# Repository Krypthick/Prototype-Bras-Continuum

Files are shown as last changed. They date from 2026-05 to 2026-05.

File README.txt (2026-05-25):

Base:

base_housing:
Le boîtier principal agit comme une base pour le bras. Il utilise des inserts chauffants filetés et des boulons M3.
Il contient :
	-circuit principal
	-circuit des pilotes pas à pas
	-circuit du système de gestion de batterie
	-les batteries
	-interrupteur
	-prise cylindrique DC

==============================
base_battery_retainer:
La pièce qui maintient les batteries en place.

==============================
base_motion_motor_housing:
Couvercle qui s'attache au boîtier avec des boulons M3 et tient les moteurs pas à pas.

==============================
base_fixed_segment:
Premier segment.

==============================
base_spacer_fixed_segment:
Espaceur entre (base_fixed_segment) et (base_motion_motor_housing), fixé avec des boulons M5. Fournit l'espace nécessaire pour les poulies attachées au réducteur.

============================================================
Gearbox:

gearbox_motor_gear:
Engrenage attaché et entraîné par le moteur pas à pas. Engrenage soleil.

==============================
gearbox_planet_gear:
Engrenage planète, aussi appelé satellite. Il y en a trois pour avoir un réducteur stable.

==============================
gearbox_ring_gear:
L'engrenage fixé au moteur pas à pas avec des boulons M3 a aussi comme fonction de contenir les pièces du réducteur.

==============================
gearbox_orbit:
La pièce qui relie les trois engrenages planètes et est attachée à l'arbre avec des boulons et écrous M4.

==============================
gearbox_shaft:
L'arbre attaché aux engrenages planètes et auquel on attache la poulie.

==============================
gearbox_shaft_attachment:
La poulie qui tient la corde permettant le mouvement du bras.

======================================================
Hand:

hand_segment:
Le dernier segment qui tient le support de la main avec des boulons et écrous M5 et tient la fin de la corde.

==============================

hand_motor_finger_mount:
Le support qui tient le petit moteur pas à pas avec des boulons M3 ainsi que les deux doigts de la pince avec des boulons M5.

==============================

hand_gripper:
Le doigt de la pince qui contient un roulement à billes 606z.

==============================

hand_bearing_M5_spacer:
La pièce qui relie le boulon M5 de diamètre 5 mm et le roulement à billes ayant un diamètre intérieur de 6 mm.

======================================================
Manette:

manette_housing:
Boîtier de la manette qui contient le circuit de la manette, la batterie 9V et le joystick. Il utilise des inserts chauffants filetés et des boulons M3.

==============================
manette_lid:
Le couvercle du boîtier de la manette attaché avec des boulons M3.

==============================
manette_pin:
La pièce qui permet d'utiliser les boutons de la manette plus facilement depuis l'extérieur.

======================================================
Segment:

La pièce principale qui guide la corde et donne la flexibilité nécessaire pour le mouvement du bras. Chaque segment a un boulon et un écrou M4, mais aussi une boule filetée de 10 mm de diamètre qui permet la rotation entre les différents segments.

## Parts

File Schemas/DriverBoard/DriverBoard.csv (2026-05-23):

Reference | Qty | Value | MAN | MPN | DPN | Footprint | Datasheet
A1,A2,A3,A4 | 4 | Pololu_Breakout_A4988 |  |  |  | Footprints:MODULE_A4988_STEPPER_MOTOR_DRIVER_CARRIER | https://www.pololu.com/product/2980/pictures
C1,C2,C7,C8 | 4 | 100uF | Würth Elektronik | 865080343009 | 732-8419-6-ND | Footprints:WCAP-ASLI_6.3X5.5_DXL_ | ~
C3,C4,C5,C6 | 4 | 100nF | KEMET | C0603C104K5RACTU | 399-C0603C104K5RACTUCT-ND | Capacitor_SMD:C_0603_1608Metric_Pad1.08x0.95mm_HandSolder | ~
C_Bulk1 | 1 | 1000uF | Chemi-Con | APSG160ELL102MJB5S | 565-3621-ND | Footprints:CHEMI-JB5 | ~
D1 | 1 | LED | Lite-On Inc. | LTST-C171KGKT | 160-1426-1-ND | LED_SMD:LED_0603_1608Metric_Pad1.05x0.95mm_HandSolder | ~
H1,H2,H3,H4 | 4 | MountingHole | - | - | - | MountingHole:MountingHole_3.2mm_M3_DIN965_Pad | ~
J1 | 1 | Conn_02x08_Counter_Clockwise | Molex | 0702461601 | WM9221-ND | Footprints:CONN_7024616xx_MOL | ~
J2 | 1 | XT30 | DFRobot | FIT0586 | 1738-1436-ND | Connector_AMASS:AMASS_XT30U-F_1x02_P5.0mm_Vertical | ~
M1,M2,M3,M4 | 4 | Stepper_Motor_bipolar | - | - | - | Footprints:CONN_SDA-41791_M450_04_MOL | http://www.infineon.com/dgdl/Application-Note-TLE8110EE_driving_UniPolarStepperMotor_V1.1.pdf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
R1 | 1 | 1k5 | Panasonic Electronic Components | ERA-3AEB152V | P1.5KDBCT-ND | Resistor_SMD:R_0603_1608Metric_Pad0.98x0.95mm_HandSolder | ~
R2,R3,R4,R5 | 4 | 10k | YAGEO | RC0603FR-0710KL | 311-10.0KHRCT-ND | Resistor_SMD:R_0603_1608Metric_Pad0.98x0.95mm_HandSolder | ~
TP1 | 1 | Test 1A | - | - | - | TestPoint:TestPoint_Pad_2.5x2.5mm | ~
TP2 | 1 | Test2A | - | - | - | TestPoint:TestPoint_Pad_2.5x2.5mm | ~

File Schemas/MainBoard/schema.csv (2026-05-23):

Reference | Qty | Value | MAN | MPN | DPN | Footprint
R23 | 1 | 270k | YAGEO | RC0603FR-07270KL | 311-270KHRCT-ND | Resistor_SMD:R_0603_1608Metric_Pad0.98x0.95mm_HandSolder
R18 | 1 | 10k | YAGEO | RC0805JR-0710KL | 311-10KARCT-ND | Resistor_SMD:R_0805_2012Metric_Pad1.20x1.40mm_HandSolder
R16 | 1 | 60k | YAGEO | RT0603BRD0760KL | 13-RT0603BRD0760KLCT-ND | Resistor_SMD:R_0603_1608Metric_Pad0.98x0.95mm_HandSolder
R4 | 1 | 470 | YAGEO | RC0603JR-07470RL | 311-470GRCT-ND | Resistor_SMD:R_0603_1608Metric_Pad0.98x0.95mm_HandSolder
R3 | 1 | 52.3k | YAGEO | RC0603FR-0752K3L | 311-52.3KHRCT-ND | Resistor_SMD:R_0603_1608Metric_Pad0.98x0.95mm_HandSolder
R1,R6,R7,R8,R9,R10,R12 | 7 | 10k | YAGEO | RC0603FR-0710KL | 311-10.0KHRCT-ND | Resistor_SMD:R_0603_1608Metric_Pad0.98x0.95mm_HandSolder
J5 | 1 | Conn_01x04 | Würth Elektronik | 61300411121 | 732-5317-ND | Connector_PinHeader_2.54mm:PinHeader_1x04_P2.54mm_Vertical
R17 | 1 | 470k | Vishay Dale | CRCW0805470KJNEA | 541-470KACT-ND | Resistor_SMD:R_0805_2012Metric_Pad1.20x1.40mm_HandSolder
R13,R14,R15 | 3 | 0 | Vishay Dale | CRCW08050000Z0EA | 541-0.0ACT-ND | Footprints:RESC2012X50N
L2 | 1 | 10uH | Vishay Dale | IHLP4040DZER100M01 | 541-1295-1-ND | Footprints:IND_IHLP-4040DZ_VIS
U1 | 1 | TPS54331DR | Texas Instruments | TPS54331DR | 296-26991-1-ND | Footprints:SOIC127P599X175-8N
PS1 | 1 | TPS62162DSGR | Texas Instruments | TPS62162DSGR | 296-43671-1-ND | Footprints:SON50P200X200X80-9N
R19,R20,R21 | 3 | 220 | TE Connectivity Passive Product | CRGCQ0805F220R | A129741CT-ND | Resistor_SMD:R_0603_1608Metric_Pad0.98x0.95mm_HandSolder
L1 | 1 | 2.2uH | Taiyo Yuden | BRL3225T2R2M | 587-2165-1-ND | Footprints:INDC3225X170N
C5,C14 | 2 | 10uF | Taiyo Yuden | LMK212BJ106KG-T | 587-1300-1-ND | Capacitor_SMD:C_0805_2012Metric_Pad1.18x1.45mm_HandSolder
U3 | 1 | STM32F103C8T6 | STMicroelectronics | STM32F103C8T6 | 497-6063-ND | Footprints:QFP50P900X900X160-48N
D5 | 1 | ESDA5V3L | STMicroelectronics | ESDA5V3L | 497-6632-1-ND | Package_TO_SOT_SMD:SOT-23-3
R2,Ren1 | 2 | 100k | Stackpole Electronics Inc | RMCF0603FT100K | RMCF0603FT100KCT-ND | Resistor_SMD:R_0603_1608Metric_Pad0.98x0.95mm_HandSolder
U4 | 1 | CP2102N-A02-GQFN28R | Silicon Labs | CP2102N-A02-GQFN28R | 336-5890-1-ND | Footprints:IC_CP2102N-A02-GQFN28R
C24 | 1 | 4.7uF | Samsung Electro-Mechanics | CL10A475KP8NNNC | 1276-1044-1-ND | Capacitor_SMD:C_0805_2012Metric_Pad1.18x1.45mm_HandSolder
C20,C21 | 2 | 1uF | Samsung Electro-Mechanics | CL10B105KP8NNNC | 1276-1946-1-ND | Capacitor_SMD:C_0603_1608Metric_Pad1.08x0.95mm_HandSolder
C11 | 1 | 100pF | Samsung Electro-Mechanics | CL10C101JB8NNNC | 1276-1008-1-ND | Capacitor_SMD:C_0603_1608Metric_Pad1.08x0.95mm_HandSolder
C10 | 1 | 10nF | Samsung Electro-Mechanics | CL10B103KB8NNNC | 1276-1009-1-ND | Capacitor_SMD:C_0603_1608Metric_Pad1.08x0.95mm_HandSolder
C9 | 1 | 4.7nF | Samsung Electro-Mechanics | CL10B473KB8NNNC | 1276-1063-1-ND | Capacitor_SMD:C_0603_1608Metric_Pad1.08x0.95mm_HandSolder
C6,C7,C8,C12 | 4 | 22uF | Samsung Electro-Mechanics | CL10A226MP8NUNE | 1276-1274-1-ND | Capacitor_SMD:C_0805_2012Metric_Pad1.18x1.45mm_HandSolder
C2 | 1 | 100uf | Rubycon | 35ZLH100MEFC6.3X11 | 1189-1300-ND | Footprints:CAP_YX_6P3X11_RUB
R11 | 1 | 1k5 | Panasonic Electronic Components | ERA-3AEB152V | P1.5KDBCT-ND | Resistor_SMD:R_0603_1608Metric_Pad0.98x0.95mm_HandSolder
R5 | 1 | 8.2k | Panasonic Electronic Components | ERJ-3EKF8201V | P8.20KHCT-ND | Resistor_SMD:R_0603_1608Metric_Pad0.98x0.95mm_HandSolder
Q1,Q2 | 2 | SS8550DTA | onsemi | SS8550DTA | SS8550DTACT-ND | Footprints:TO-92-3L_5P33X5P2_ONS
J1 | 1 | Conn_02x08_Counter_Clockwise | Molex | 0702461601 | WM9221-ND | Footprints:CONN_7024616xx_MOL
D8 | 1 | LEDR | Lite-On Inc. | LTST-C171KGKT | 160-1426-1-ND | LED_SMD:LED_0805_2012Metric_Pad1.15x1.40mm_HandSolder
D7 | 1 | LEDO | Lite-On Inc. | LTST-C171KGKT | 160-1426-1-ND | LED_SMD:LED_0805_2012Metric_Pad1.15x1.40mm_HandSolder
D6 | 1 | LEDV | Lite-On Inc. | LTST-C171KGKT | 160-1426-1-ND | LED_SMD:LED_0805_2012Metric_Pad1.15x1.40mm_HandSolder
D2 | 1 | LED | Lite-On Inc. | LTST-C171KGKT | 160-1426-1-ND | LED_SMD:LED_0805_2012Metric_Pad1.15x1.40mm_HandSolder
FB1 | 1 | 120 | Laird-Signal Integrity Products | MI0603M121R-10 | 240-2375-1-ND | Inductor_SMD:L_0603_1608Metric_Pad1.05x0.95mm_HandSolder
C28 | 1 | 100nF | KEMET | C0805C104K5RACTU | 399-C0805C104K5RACTUCT-ND | Capacitor_SMD:C_0805_2012Metric_Pad1.18x1.45mm_HandSolder
C25,C26 | 2 | 10pF | KEMET | C0603C100J5GACTU | 399-C0603C100J5GACTUCT-ND | Capacitor_SMD:C_0603_1608Metric_Pad1.08x0.95mm_HandSolder
C1,C3,C4,C13,C15,C16,C17,C18,C19,C22,C23,C27 | 12 | 100nF | KEMET | C0603C104K5RACTU | 399-C0603C104K5RACTUCT-ND | Capacitor_SMD:C_0603_1608Metric_Pad1.08x0.95mm_HandSolder
U2 | 1 | ESP32-WROOM-32E | Espressif Systems | ESP32-WROOM-32E-N4 | 1965-ESP32-WROOM-32E-N4CT-ND | Footprints:XCVR_ESP32-WROOM-32E__16MB_
J3 | 1 | XT30 | DFRobot | FIT0586 | 1738-1436-ND | Connector_AMASS:AMASS_XT30U-M_1x02_P5.0mm_Vertical
D1,D3,D4 | 3 | D_Schottky | Comchip Technology | CDBC560-G | 641-1127-1-ND | Footprints:CDBC-G
SW2,SW4 | 2 | BOOT | C&K | PTS636SK25FSMTR LFS | CKN12330-1-ND | Button_Switch_SMD:SW_Tactile_SPST_NO_Straight_CK_PTS636Sx25SMTRLFS
SW1 | 1 | EN | C&K | PTS636SK25FSMTR LFS | CKN12330-1-ND | Button_Switch_SMD:SW_Tactile_SPST_NO_Straight_CK_PTS636Sx25SMTRLFS
J2,J4 | 2 | USB_B_Micro | Amphenol ICC (FCI) | 10118192-0001LF | 609-4613-1-ND | Footprints:AMPHENOL_10118192-0001LF
Y1 | 1 | 16MHz | Abracon LLC | ABM8G-16.000MHZ-18-D2Y-T | 535-10267-1-ND | Crystal:Crystal_SMD_2520-4Pin_2.5x2.0mm
TP1,TP2,TP3,TP4,TP5 | 5 | TestPoint | - | - | - | TestPoint:TestPoint_Pad_1.5x1.5mm
H1,H2,H3,H4 | 4 | MountingHole | - | - | - | MountingHole:MountingHole_3.2mm_M3_DIN965_Pad

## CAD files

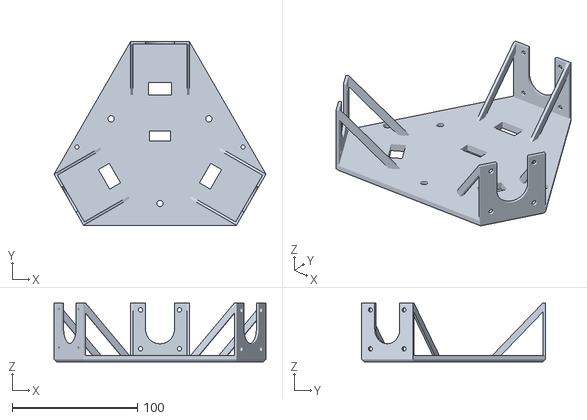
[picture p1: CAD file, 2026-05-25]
Models_du_project/base/base_motion_motor_housing.stl
168.9 x 146.3 x 47.0

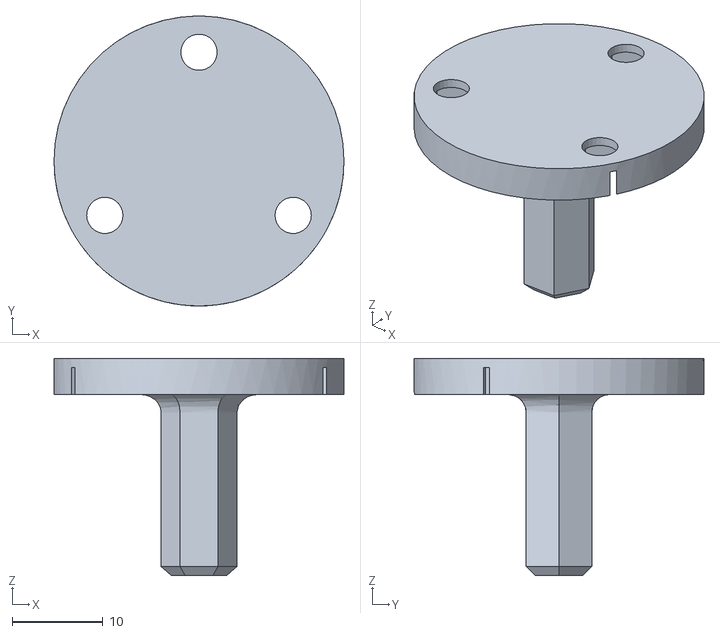
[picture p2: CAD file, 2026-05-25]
Models_du_project/gearbox/gearbox_shaft.stl
32.0 x 32.0 x 24.0

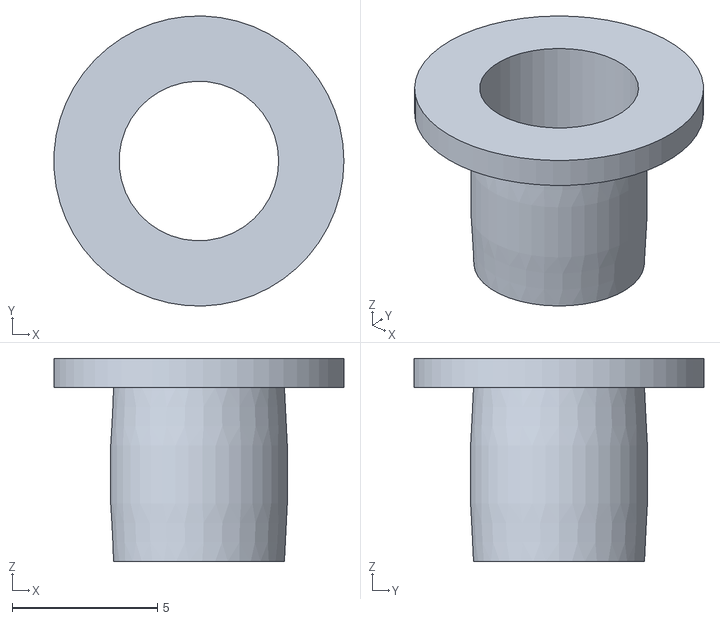
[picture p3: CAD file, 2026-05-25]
Models_du_project/hand/hand_bearing_M5_spacer.stl
9.99 x 10.00 x 7.00

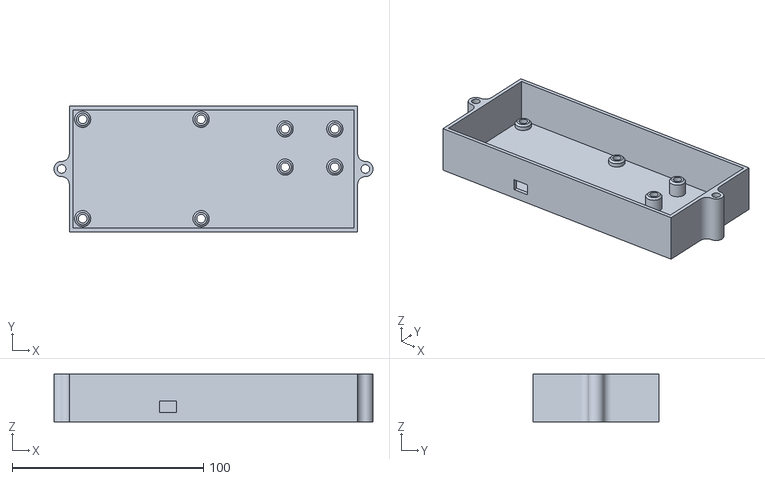
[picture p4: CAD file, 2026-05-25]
Models_du_project/manette/manette_housing.stl
167.0 x 66.0 x 25.0

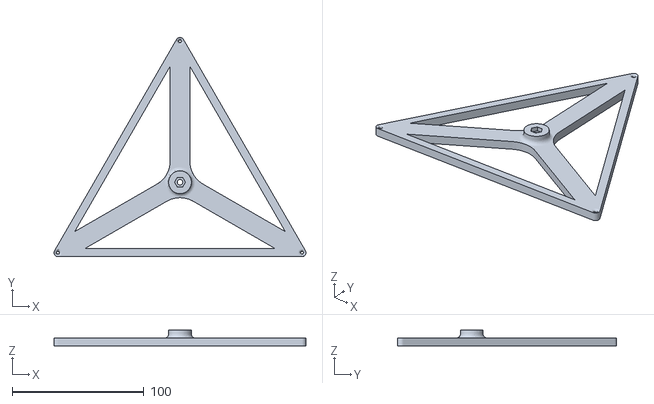
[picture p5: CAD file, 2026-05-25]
Models_du_project/segment.stl
191.3 x 166.5 x 12.0

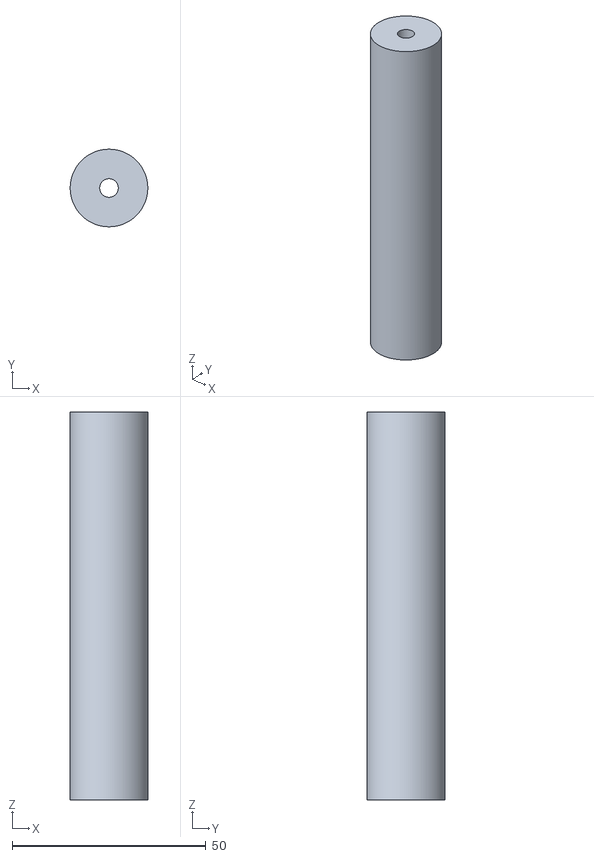
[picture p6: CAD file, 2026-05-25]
Models_du_project/base/base_spacer_fixed_segment.stl
20.0 x 20.0 x 100.0

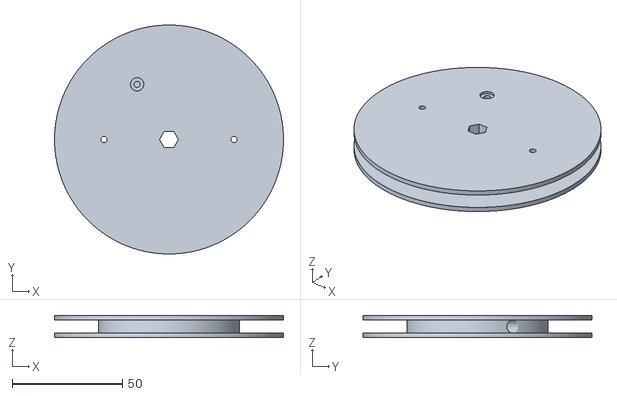
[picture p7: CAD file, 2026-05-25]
Models_du_project/gearbox/gearbox_shaft_attachment.stl
103.7 x 103.6 x 10.0

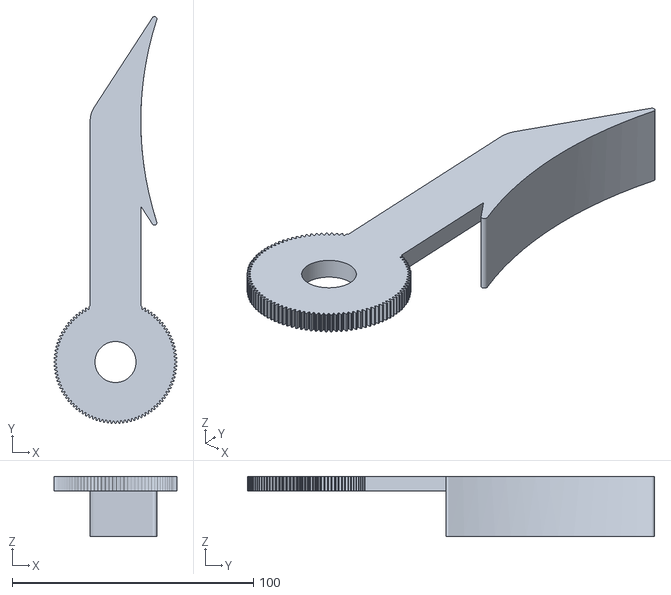
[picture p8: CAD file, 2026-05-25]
Models_du_project/hand/hand_gripper.stl
51.0 x 168.8 x 25.0

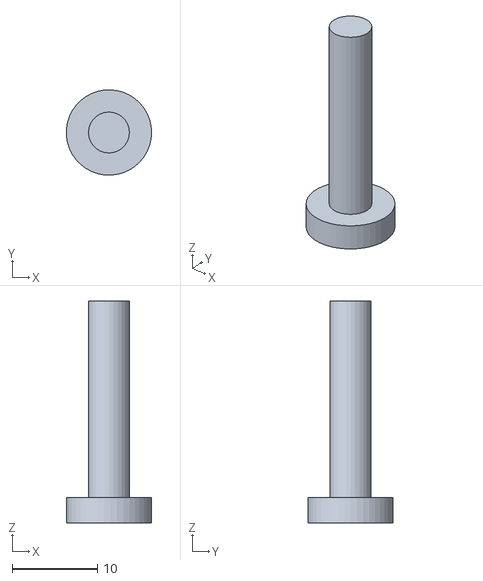
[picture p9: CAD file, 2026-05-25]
Models_du_project/manette/manette_pin.stl
9.99 x 9.99 x 26.0

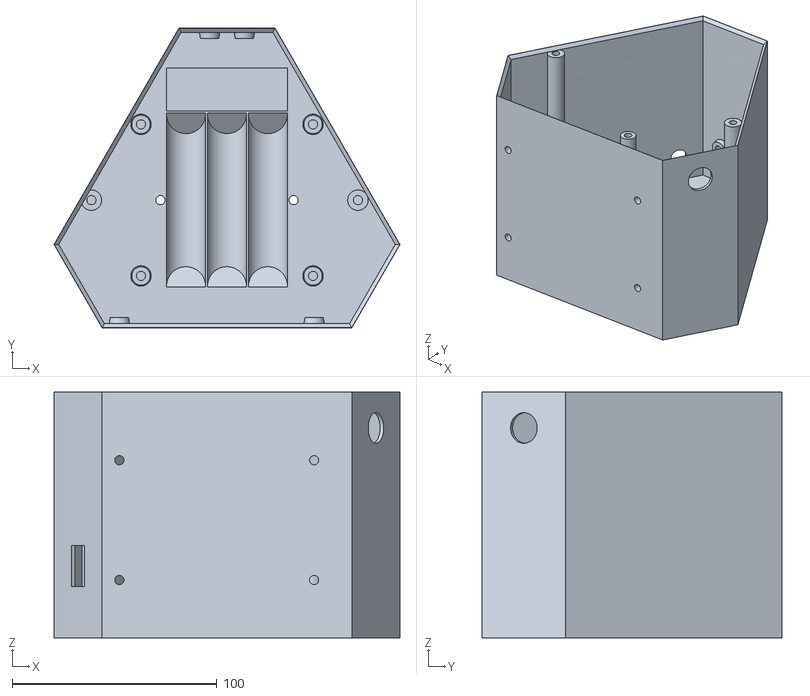
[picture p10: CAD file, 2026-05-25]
Models_du_project/base/base_housing.stl
168.9 x 146.3 x 120.0

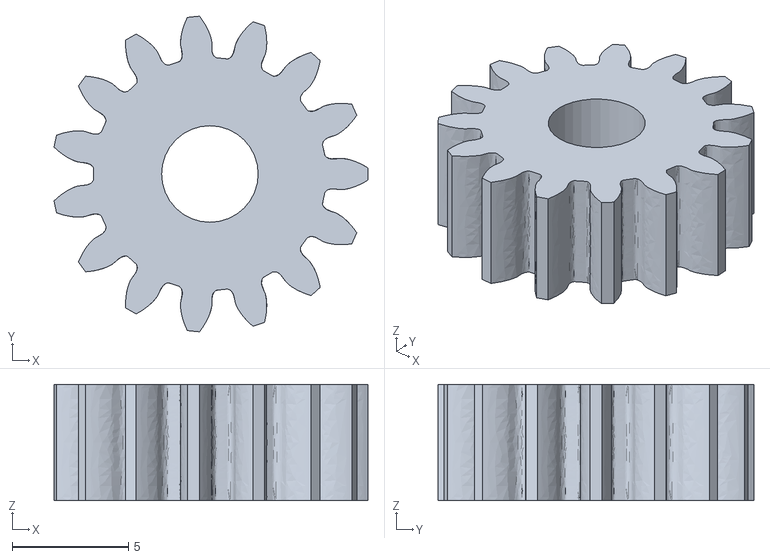
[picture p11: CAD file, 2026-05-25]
Models_du_project/gearbox/gearbox_planet_gear.stl
13.5 x 13.6 x 5.00

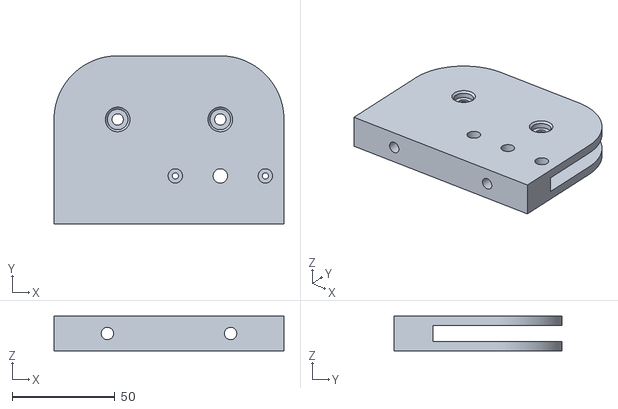
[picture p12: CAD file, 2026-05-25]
Models_du_project/hand/hand_motor_finger_mount.stl
112.0 x 82.0 x 17.0

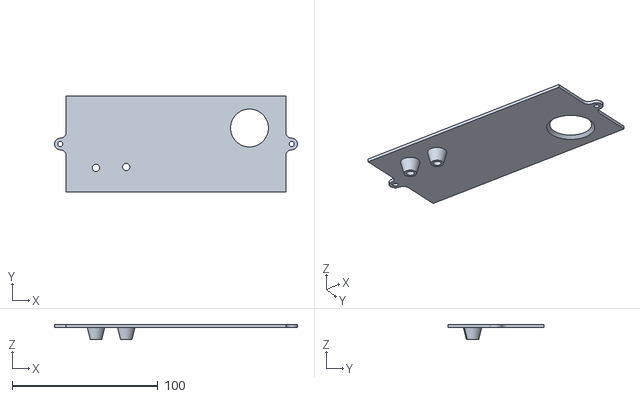
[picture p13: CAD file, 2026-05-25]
Models_du_project/manette/manette_lid.stl
167.0 x 66.0 x 10.0

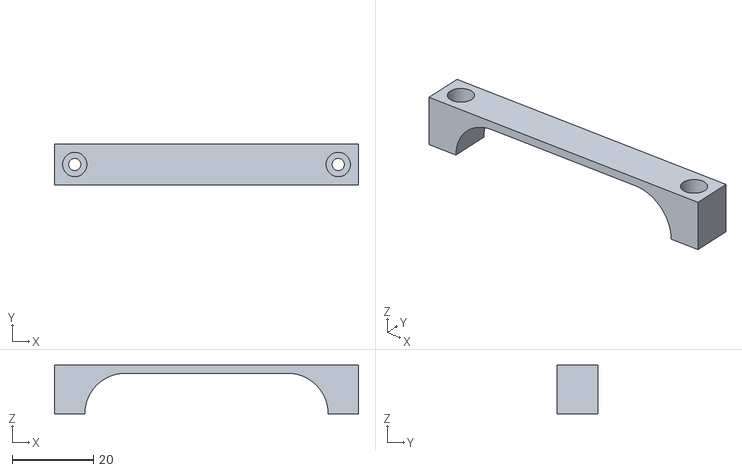
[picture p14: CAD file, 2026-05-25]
Models_du_project/base/base_battery_retainer.stl
75.0 x 10.0 x 12.0

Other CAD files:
Models_du_project/gearbox/gearbox_ring_gear.stl
Models_du_project/hand/hand_segment.stl
Models_du_project/base/base_fixed_segment.stl
Models_du_project/gearbox/gearbox_motor_gear.stl
Models_du_project/gearbox/gearbox_orbit.stl

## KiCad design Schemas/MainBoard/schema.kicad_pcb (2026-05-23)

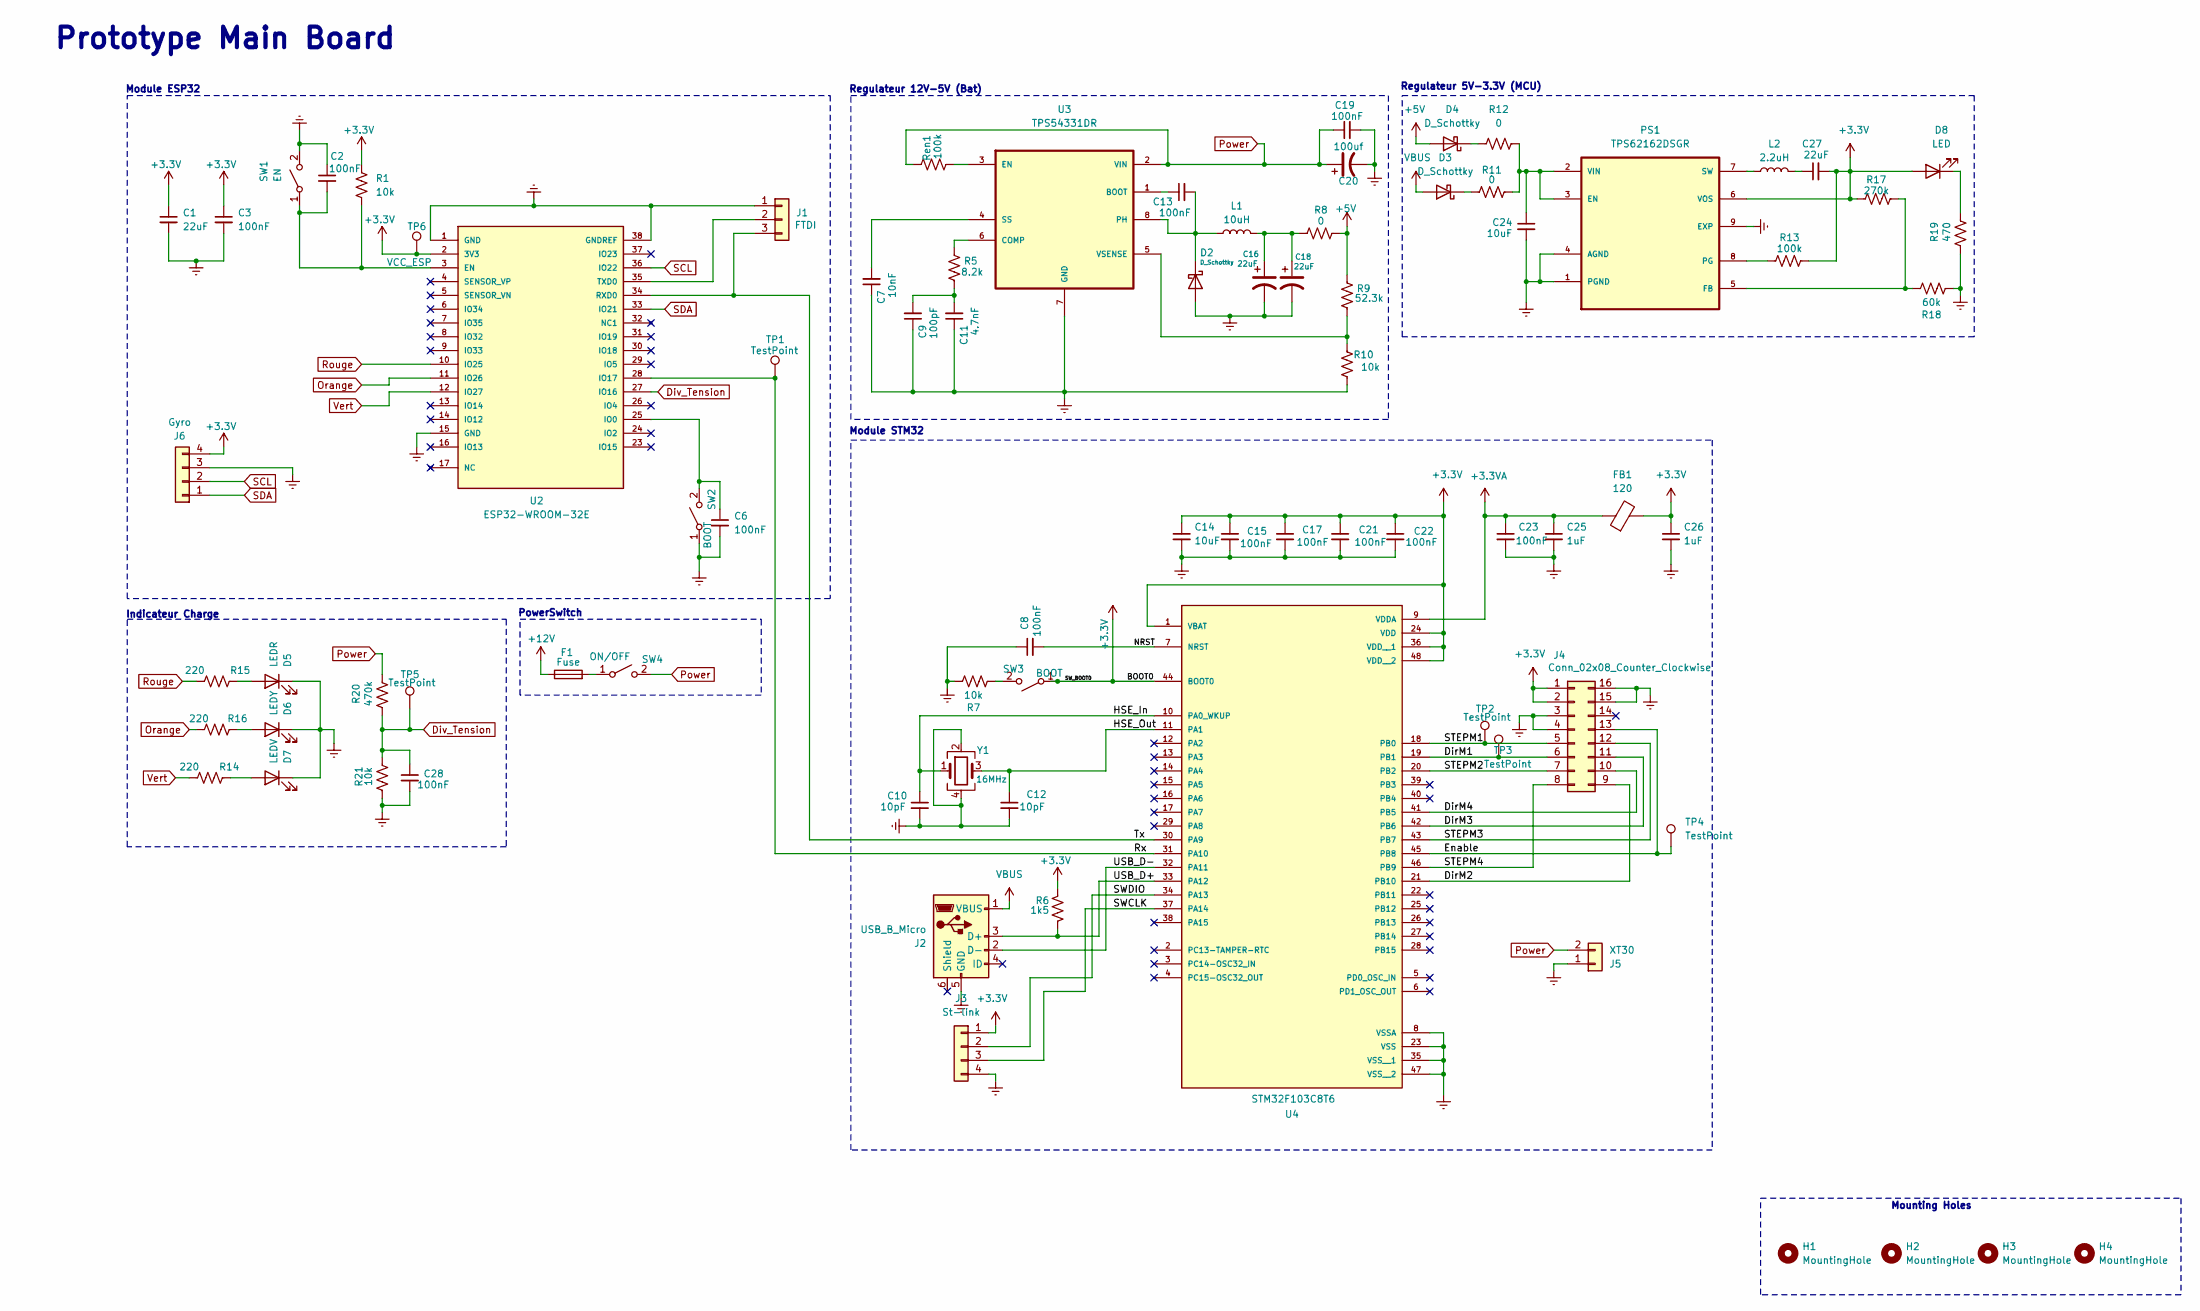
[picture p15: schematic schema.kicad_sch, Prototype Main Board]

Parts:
C1, C16, C18, C27: 22uF; C_0805_2012Metric_Pad1.18x1.45mm_HandSolder; MPN CL10A226MP8NUNE
C2, C3, C6, C8, C13, C15, C17, C19, C21, C22, C23: 100nF; C_0603_1608Metric_Pad1.08x0.95mm_HandSolder; MPN C0603C104K5RACTU
C7: 10nF; C_0603_1608Metric_Pad1.08x0.95mm_HandSolder; MPN CL10B103KB8NNNC
C9: 100pF; C_0603_1608Metric_Pad1.08x0.95mm_HandSolder; MPN CL10C101JB8NNNC
C10, C12: 10pF; C_0603_1608Metric_Pad1.08x0.95mm_HandSolder; MPN C0603C100J5GACTU
C11: 4.7nF; C_0603_1608Metric_Pad1.08x0.95mm_HandSolder; MPN CL10B473KB8NNNC
C14, C24: 10uF; C_0805_2012Metric_Pad1.18x1.45mm_HandSolder; MPN CL21B106KOQNNNE
C20: 100uf; CAP_YX_6P3X11_RUB; MPN 35ZLH100MEFC6.3X11
C25, C26: 1uF; C_0603_1608Metric_Pad1.08x0.95mm_HandSolder; MPN CL10B105KP8NNNC
C28: 100nF; C_0805_2012Metric_Pad1.18x1.45mm_HandSolder; MPN C0805C104K5RACTU
D2, D3, D4: D_Schottky; CDBC-G; MPN CDBC560-G
D5: LEDR; LED_0805_2012Metric_Pad1.15x1.40mm_HandSolder; MPN LTST-C171KRKT
D6: LEDY; LED_0805_2012Metric_Pad1.15x1.40mm_HandSolder; MPN LTST-C171KSKT
D7: LEDV; LED_0805_2012Metric_Pad1.15x1.40mm_HandSolder; MPN LTST-C171KGKT
D8: LED; LED_0805_2012Metric_Pad1.15x1.40mm_HandSolder; MPN LTST-C171KGKT
F1: Fuse; FUSC6125X279N; MPN 0679H9100-05
FB1: 120; L_0603_1608Metric_Pad1.05x0.95mm_HandSolder; MPN MI0603M121R-10
H1, H2, H3, H4: MountingHole; MountingHole_3.2mm_M3_DIN965_Pad
J1: FTDI; PinHeader_1x03_P2.54mm_Vertical
J2: USB_B_Micro; AMPHENOL_10118192-0001LF; MPN 10118192-0001LF
J3: St-link; PinHeader_1x04_P2.54mm_Vertical; MPN 61300411121
J4: Conn_02x08_Counter_Clockwise; CONN_7024616xx_MOL; MPN 0702461601
J5: XT30; AMASS_XT30U-M_1x02_P5.0mm_Vertical; MPN FIT0586
J6: Gyro; PinHeader_1x04_P2.54mm_Vertical; MPN 61300411121
L1: 10uH; IND_IHLP-4040DZ_VIS; MPN IHLP4040DZER100M01
L2: 2.2uH; INDC3225X170N; MPN BRL3225T2R2M
PS1: TPS62162DSGR; SON50P200X200X80-9N; PARTREV E
R1, R7, R10: 10k; R_0603_1608Metric_Pad0.98x0.95mm_HandSolder; MPN RC0603FR-0710KL
R5: 8.2k; R_0603_1608Metric_Pad0.98x0.95mm_HandSolder; MPN ERJ-3EKF8201V
R6: 1k5; R_0603_1608Metric_Pad0.98x0.95mm_HandSolder; MPN ERA-3AEB152V
R8, R11, R12: 0; RESC2012X50N; MPN CRCW08050000Z0EA
R9: 52.3k; R_0603_1608Metric_Pad0.98x0.95mm_HandSolder; MPN RC0603FR-0752K3L
R13: 100k; R_0603_1608Metric_Pad0.98x0.95mm_HandSolder; MPN RMCF0603FT100K
R14, R15, R16: 220; R_0603_1608Metric_Pad0.98x0.95mm_HandSolder; MPN CRGCQ0805F220R
R17: 270k; R_0603_1608Metric_Pad0.98x0.95mm_HandSolder; MPN RC0603FR-07270KL
R18: 60k; R_0603_1608Metric_Pad0.98x0.95mm_HandSolder; MPN RT0603BRD0760KL
R19: 470; R_0603_1608Metric_Pad0.98x0.95mm_HandSolder; MPN RC0603JR-07470RL
R20: 470k; R_0805_2012Metric_Pad1.20x1.40mm_HandSolder; MPN CRCW0805470KJNEA
R21: 10k; R_0805_2012Metric_Pad1.20x1.40mm_HandSolder; MPN RC0805JR-0710KL
Ren1: 100k; R_0603_1608Metric_Pad0.98x0.95mm_HandSolder; MPN RMCF0603FT100K
SW1: EN; SW_Tactile_SPST_NO_Straight_CK_PTS636Sx25SMTRLFS; MPN PTS636SK25FSMTR LFS
SW2, SW3: BOOT; SW_Tactile_SPST_NO_Straight_CK_PTS636Sx25SMTRLFS; MPN PTS636SK25FSMTR LFS
SW4: ON/OFF; TE_640456-2; MPN R1966ABLKBLKFF
TP1, TP2, TP3, TP4, TP5: TestPoint; TestPoint_Pad_1.5x1.5mm
TP6: VCC_ESP; TestPoint_Pad_1.5x1.5mm
U2: ESP32-WROOM-32E; XCVR_ESP32-WROOM-32E__16MB_; PARTREV 1.4
U3: TPS54331DR; SOIC127P599X175-8N; MPN TPS54331DR
U4: STM32F103C8T6; QFP50P900X900X160-48N; PARTREV 10
Y1: 16MHz; Crystal_SMD_2520-4Pin_2.5x2.0mm; MPN ABM8G-16.000MHZ-18-D2Y-T

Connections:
+3.3V: C1.1, C3.1, C14.1, C15.1, C17.1, C21.1, C22.1, C26.1, C27.2, D8.2 (A), FB1.2, J3.1, J4.1, J4.2, J6.4, PS1.6 (VOS), R1.1, R6.2, R13.2, R17.2, SW3.1 (A), TP6.1, U2.2 (3V3), U4.1 (VBAT), U4.24 (VDD), U4.36 (VDD__1), U4.44 (BOOT0), U4.48 (VDD__2)
+3.3VA: C23.1, C25.1, FB1.1, U4.9 (VDDA)
+5V: D4.2 (A), R8.2, R9.2
+12V: F1.1
/DirM1: J4.6, TP3.1, U4.19 (PB1)
/DirM2: J4.9, U4.21 (PB10)
/DirM3: J4.11, U4.42 (PB6)
/DirM4: J4.10, U4.41 (PB5)
/Enable: J4.13, TP4.1, U4.45 (PB8)
/HSE_In: C10.1, U4.10 (PA0_WKUP), Y1.1
/HSE_Out: C12.1, U4.11 (PA1), Y1.3
/NRST: C8.2, U4.7 (NRST)
/Rx: TP1.1, U2.28 (IO17), U4.31 (PA10)
/STEPM1: J4.5, TP2.1, U4.18 (PB0)
/STEPM2: J4.7, U4.20 (PB2)
/STEPM3: J4.12, U4.43 (PB7)
/STEPM4: J4.8, U4.46 (PB9)
/SWCLK: J3.3, U4.37 (PA14)
/SWDIO: J3.2, U4.34 (PA13)
/Tx: J1.3, U2.34 (RXD0), U4.30 (PA9)
/USB_D+: J2.3 (D+), R6.1, U4.33 (PA12)
/USB_D-: J2.2 (D-), U4.32 (PA11)
Div_Tension: C28.1, R20.1, R21.2, TP5.1, U2.27 (IO16)
unnamed: C9.2, C11.2, R5.1
unnamed: C16.1, C18.1, L1.2, R8.1
unnamed: C27.1, L2.2
unnamed: C13.2, D2.1 (K), L1.1, U3.8 (PH)
unnamed: D3.1 (K), R11.1
unnamed: D4.1 (K), R12.1
unnamed: D5.2 (A), R15.1
unnamed: D6.2 (A), R16.1
unnamed: D7.2 (A), R14.1
unnamed: D8.1 (K), R19.2
unnamed: J1.2, U2.35 (TXD0)
unnamed: C24.1, PS1.2 (VIN), PS1.3 (EN), R11.2, R12.2
unnamed: PS1.5 (FB), R17.1, R18.2
unnamed: PS1.8 (PG), R13.1
unnamed: L2.1, PS1.7 (SW)
unnamed: C2.2, R1.2, SW1.1 (A), U2.3 (EN)
unnamed: C6.1, SW2.2 (B), U2.25 (IO0)
unnamed: R7.1, SW3.2 (B)
unnamed: F1.2, SW4.1 (A)
unnamed: C13.1, U3.1 (BOOT)
unnamed: R5.2, U3.6 (COMP)
unnamed: Ren1.1, U3.3 (EN)
unnamed: C7.2, U3.4 (SS)
unnamed: R9.1, R10.2, U3.5 (VSENSE)
Orange: R16.2, U2.11 (IO26)
Power: C19.1, C20.1, J5.2, R20.2, Ren1.2, SW4.2 (B), U3.2 (VIN)
Rouge: R15.2, U2.10 (IO25)
SCL: J6.2, U2.36 (IO22)
SDA: J6.1, U2.33 (IO21)
VBUS: D3.2 (A), J2.1 (VBUS)
Vert: R14.2, U2.12 (IO27)

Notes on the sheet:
Indicateur Charge
PowerSwitch
Module ESP32
Regulateur 5V-3.3V (MCU)
Mounting Holes
Module STM32
Regulateur 12V-5V (Bat)
Prototype Main Board

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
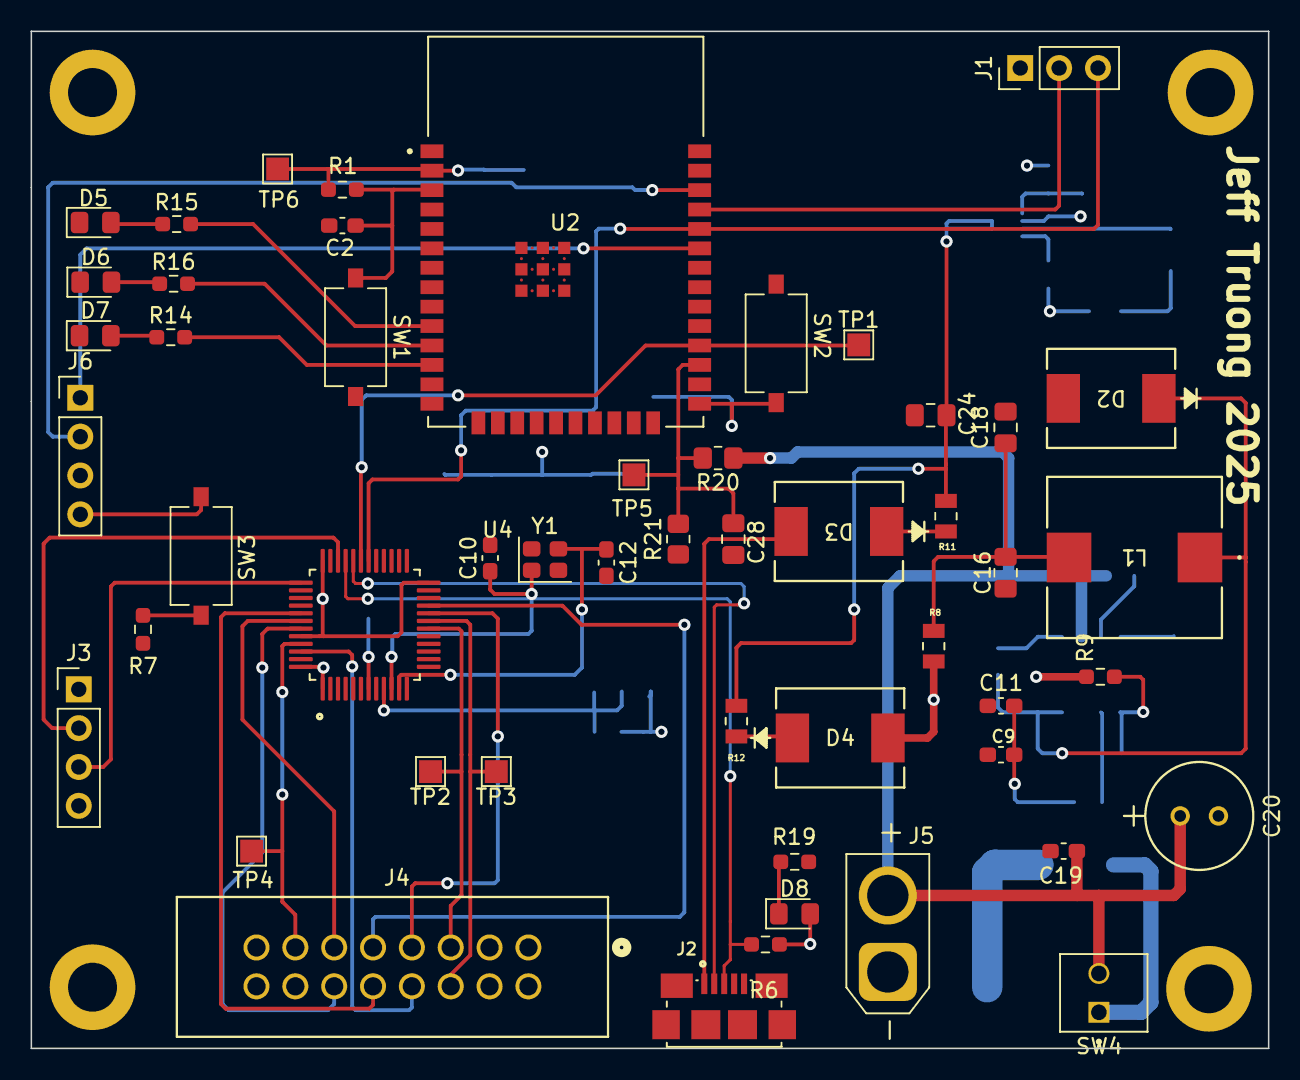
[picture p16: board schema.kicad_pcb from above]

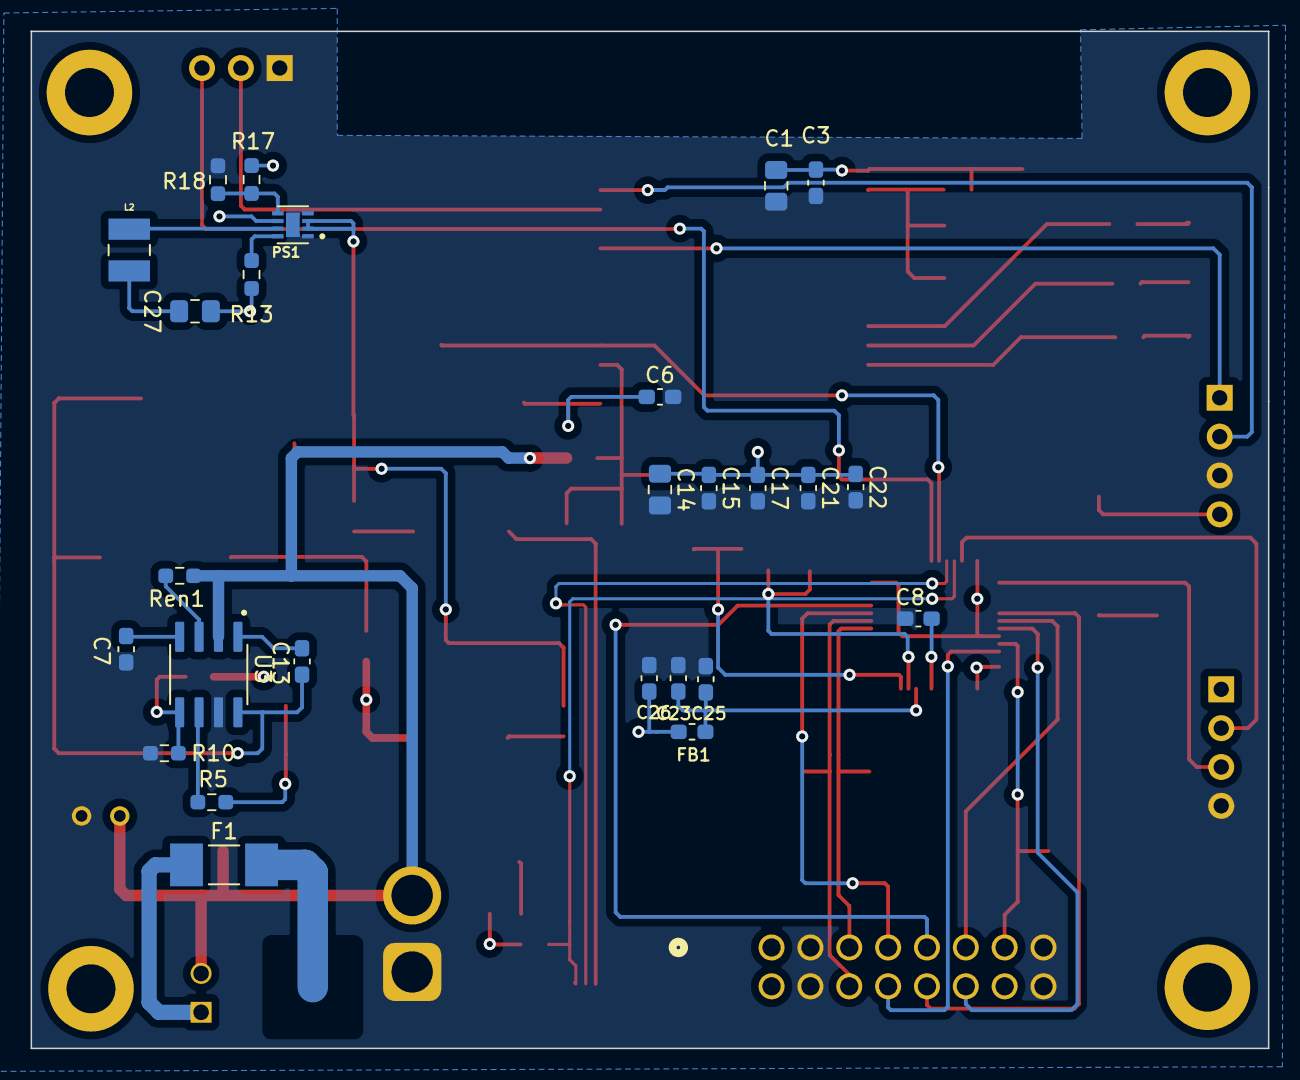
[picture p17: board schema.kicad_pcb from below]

Board: 4 copper layers, 80.9 x 66.5 mm, 81 parts (26 on the bottom side), 54 nets.

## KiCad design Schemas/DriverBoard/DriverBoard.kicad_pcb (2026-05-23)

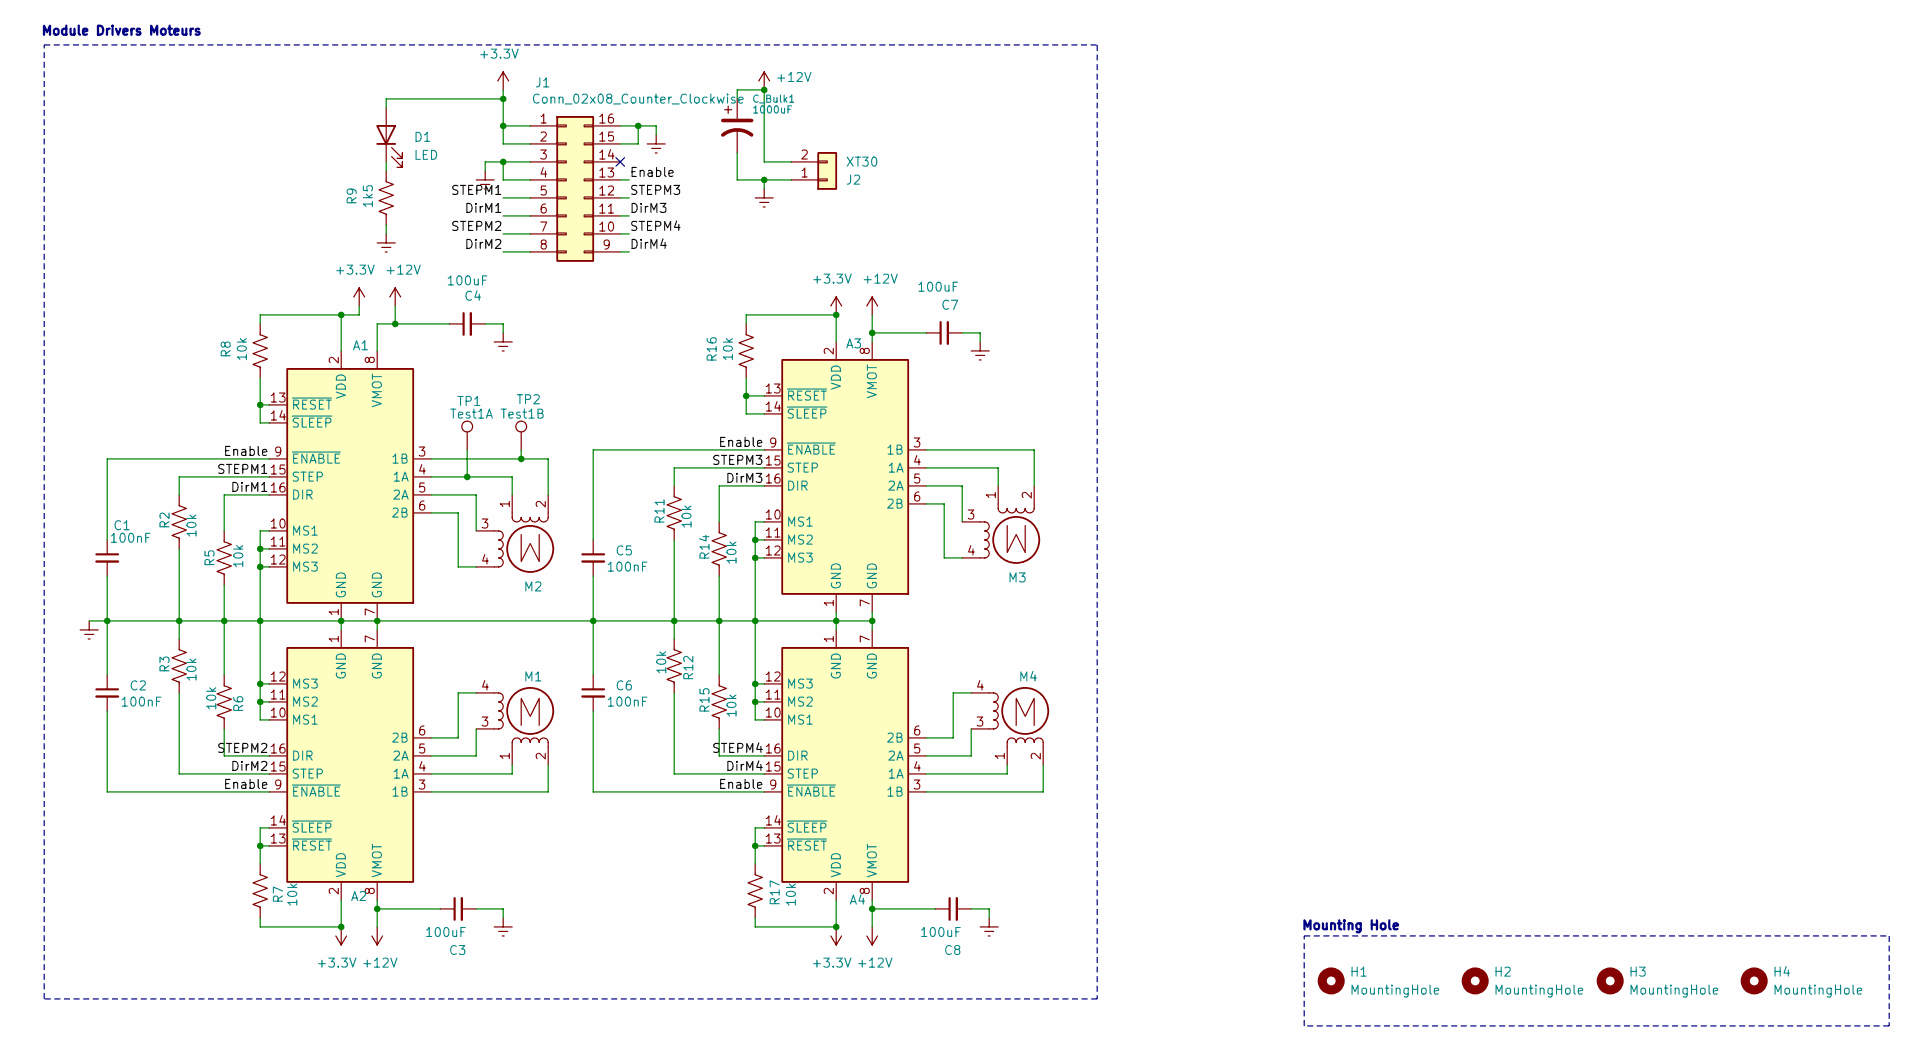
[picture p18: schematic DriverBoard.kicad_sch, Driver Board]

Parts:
A1, A2, A3, A4: Pololu_Breakout_A4988; MODULE_A4988_STEPPER_MOTOR_DRIVER_CARRIER
C1, C2, C5, C6: 100nF; C_0603_1608Metric_Pad1.08x0.95mm_HandSolder; MPN C0603C104K5RACTU
C3, C4, C7, C8: 100uF; WCAP-ASLI_6.3X5.5_DXL_; MPN 865080343009
C_Bulk1: 1000uF; CHEMI-JB5; MPN APSG160ELL102MJB5S
D1: LED; LED_0603_1608Metric_Pad1.05x0.95mm_HandSolder; MPN LTST-C171KGKT
H1, H2, H3, H4: MountingHole; MountingHole_3.2mm_M3_DIN965_Pad
J1: Conn_02x08_Counter_Clockwise; CONN_7024616xx_MOL; MPN 0702461601
J2: XT30; AMASS_XT30U-F_1x02_P5.0mm_Vertical; MPN FIT0586
M1, M2, M3, M4: Stepper_Motor_bipolar; CONN_SDA-41791_M450_04_MOL; MPN 0026604040
R2, R3, R5, R6, R7, R8, R11, R12, R14, R15, R16, R17: 10k; R_0603_1608Metric_Pad0.98x0.95mm_HandSolder; MPN RC0603FR-0710KL
R9: 1k5; R_0603_1608Metric_Pad0.98x0.95mm_HandSolder; MPN ERA-3AEB152V
TP1: Test1A; TestPoint_Pad_2.5x2.5mm
TP2: Test1B; TestPoint_Pad_2.5x2.5mm

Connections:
+3.3V: A1.2 (VDD), A2.2 (VDD), A3.2 (VDD), A4.2 (VDD), D1.2 (A), J1.1, J1.2, R7.2, R8.2, R16.2, R17.1
+12V: A1.8 (VMOT), A2.8 (VMOT), A3.8 (VMOT), A4.8 (VMOT), C3.1, C4.1, C7.1, C8.1, C_Bulk1.1, J2.2
/DirM1: A1.16 (DIR), J1.6, R5.2
/DirM2: A2.15 (STEP), J1.8, R3.2
/DirM3: A3.16 (DIR), J1.11, R14.1
/DirM4: A4.15 (STEP), J1.9, R12.1
/Enable: A1.9 (~ENABLE), A2.9 (~ENABLE), A3.9 (~ENABLE), A4.9 (~ENABLE), C1.1, C2.2, C5.1, C6.2, J1.13
/STEPM1: A1.15 (STEP), J1.5, R2.1
/STEPM2: A2.16 (DIR), J1.7, R6.1
/STEPM3: A3.15 (STEP), J1.12, R11.1
/STEPM4: A4.16 (DIR), J1.10, R15.2
GNDREF: A1.1 (GND), A1.7 (GND), A1.10 (MS1), A1.11 (MS2), A1.12 (MS3), A2.1 (GND), A2.7 (GND), A2.10 (MS1), A2.11 (MS2), A2.12 (MS3), A3.1 (GND), A3.7 (GND), A3.10 (MS1), A3.11 (MS2), A3.12 (MS3), A4.1 (GND), A4.7 (GND), A4.10 (MS1), A4.11 (MS2), A4.12 (MS3), C1.2, C2.1, C3.2, C4.2, C5.2, C6.1, C7.2, C8.2, C_Bulk1.2, J1.3, J1.4, J1.15, J1.16, J2.1, R2.2, R3.1, R5.1, R6.2, R9.1, R11.2, R12.2, R14.2, R15.1
unnamed: A1.4 (1A), M2.1, TP1.1
unnamed: A1.3 (1B), M2.2 (-), TP2.1
unnamed: A1.5 (2A), M2.3
unnamed: A1.6 (2B), M2.4
unnamed: A1.13 (~RESET), A1.14 (~SLEEP), R8.1
unnamed: A2.4 (1A), M1.1
unnamed: A2.3 (1B), M1.2 (-)
unnamed: A2.5 (2A), M1.3
unnamed: A2.6 (2B), M1.4
unnamed: A2.13 (~RESET), A2.14 (~SLEEP), R7.1
unnamed: A3.4 (1A), M3.1
unnamed: A3.3 (1B), M3.2 (-)
unnamed: A3.5 (2A), M3.3
unnamed: A3.6 (2B), M3.4
unnamed: A3.13 (~RESET), A3.14 (~SLEEP), R16.1
unnamed: A4.4 (1A), M4.1
unnamed: A4.3 (1B), M4.2 (-)
unnamed: A4.5 (2A), M4.3
unnamed: A4.6 (2B), M4.4
unnamed: A4.13 (~RESET), A4.14 (~SLEEP), R17.2
unnamed: D1.1 (K), R9.2

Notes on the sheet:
Mounting Hole
Module Drivers Moteurs

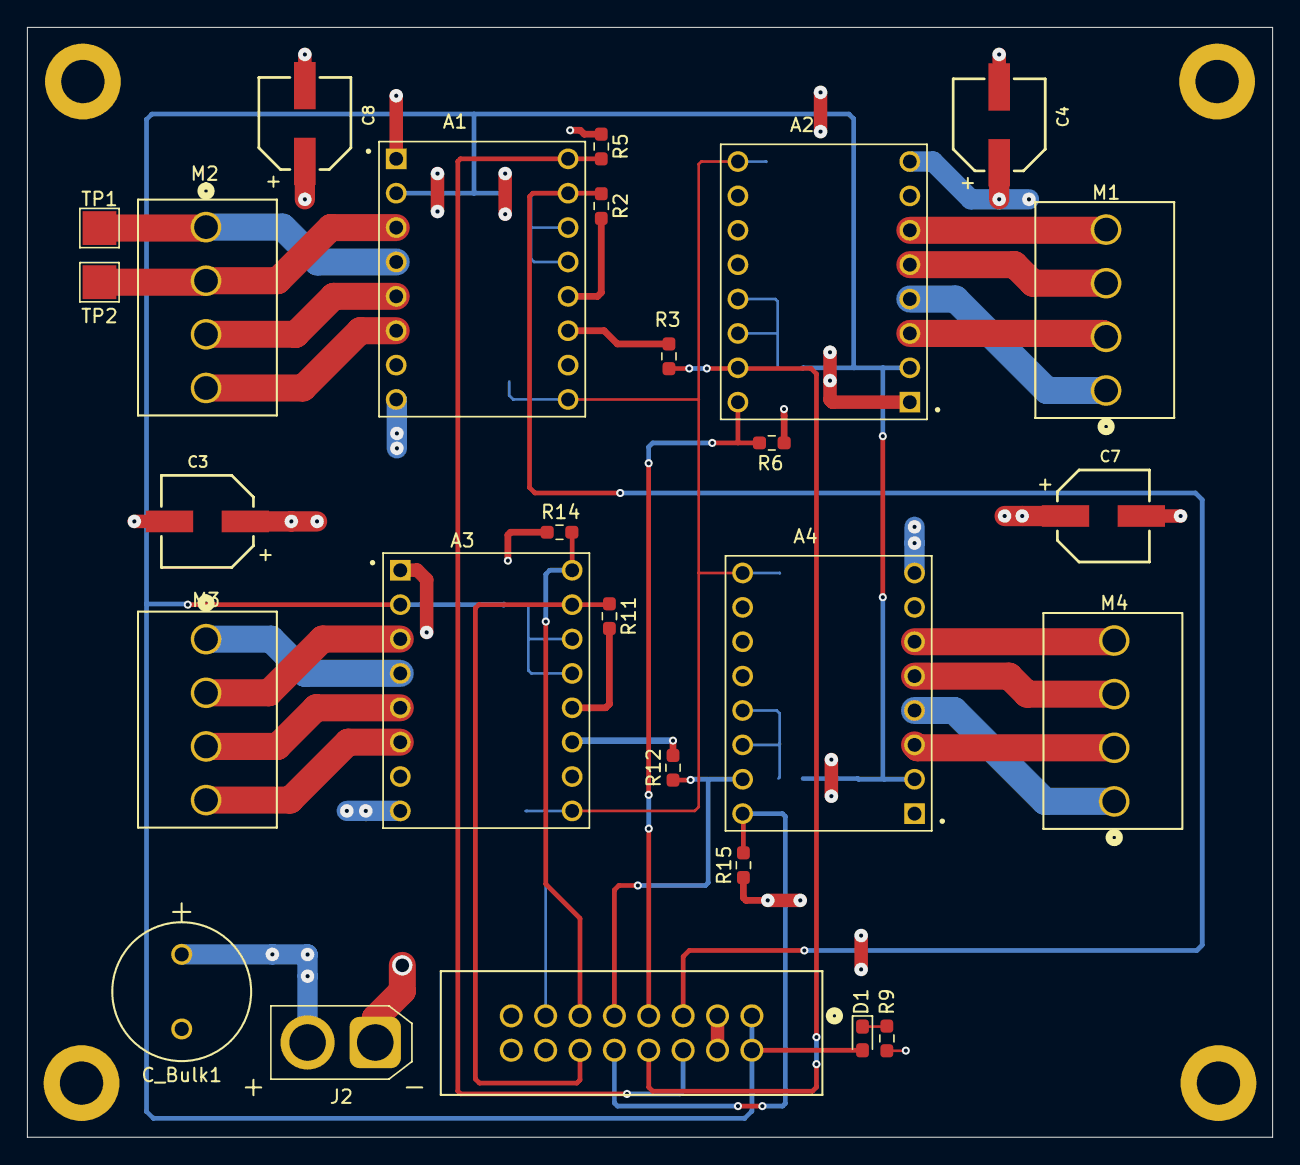
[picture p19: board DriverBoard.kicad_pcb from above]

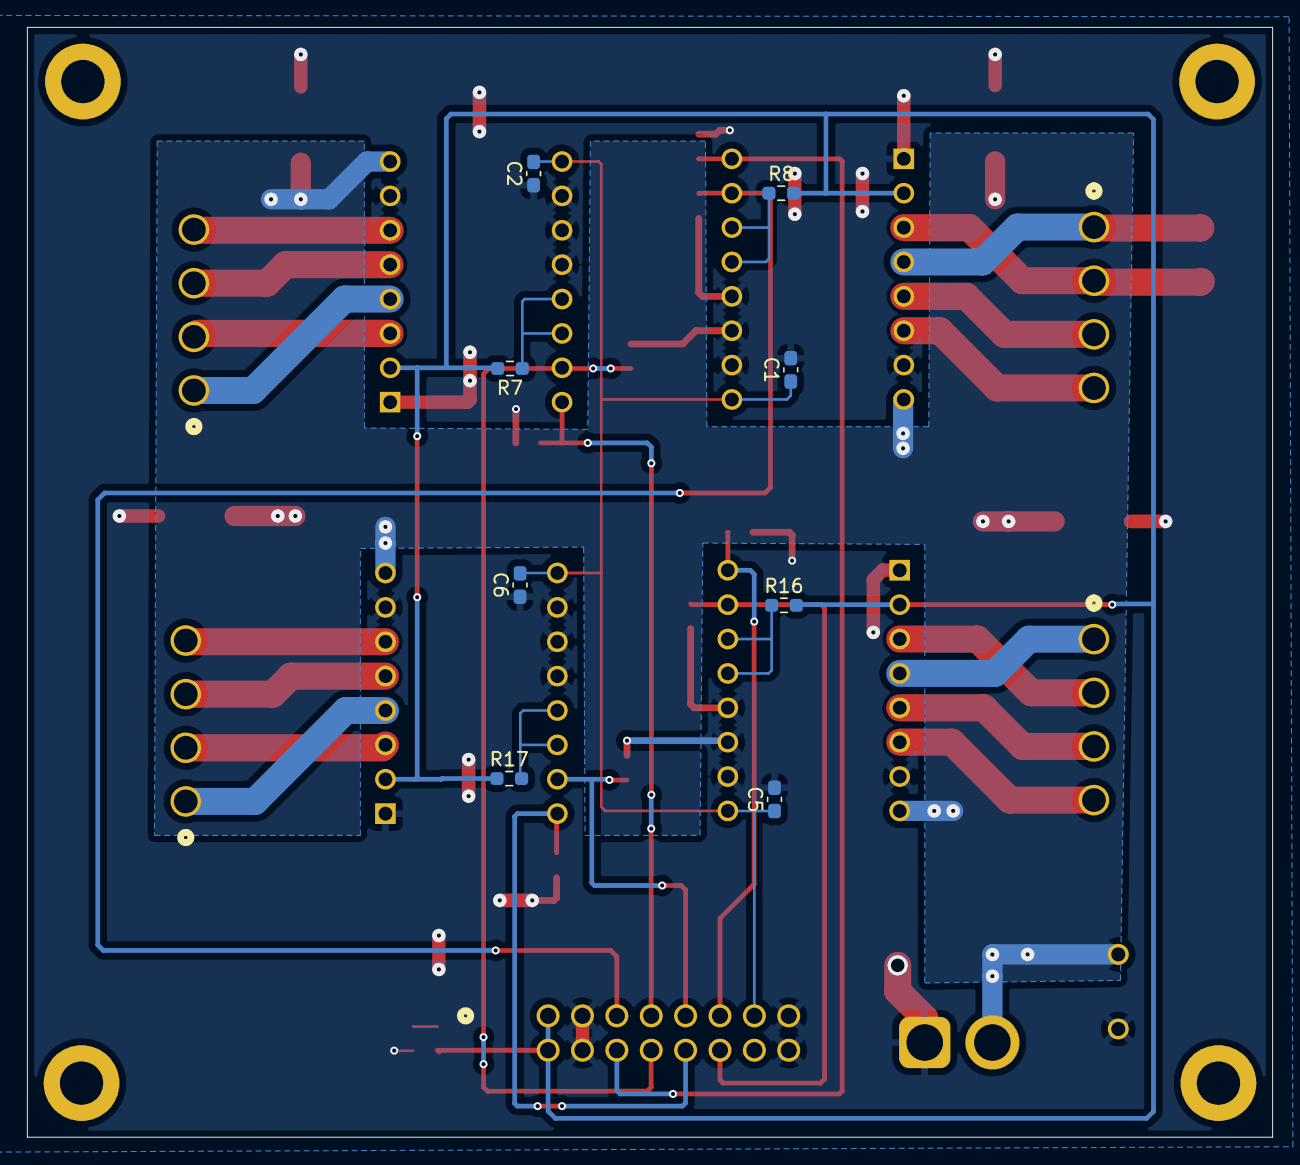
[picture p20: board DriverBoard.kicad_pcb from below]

Board: 2 copper layers, 92.0 x 82.0 mm, 39 parts (8 on the bottom side), 33 nets.

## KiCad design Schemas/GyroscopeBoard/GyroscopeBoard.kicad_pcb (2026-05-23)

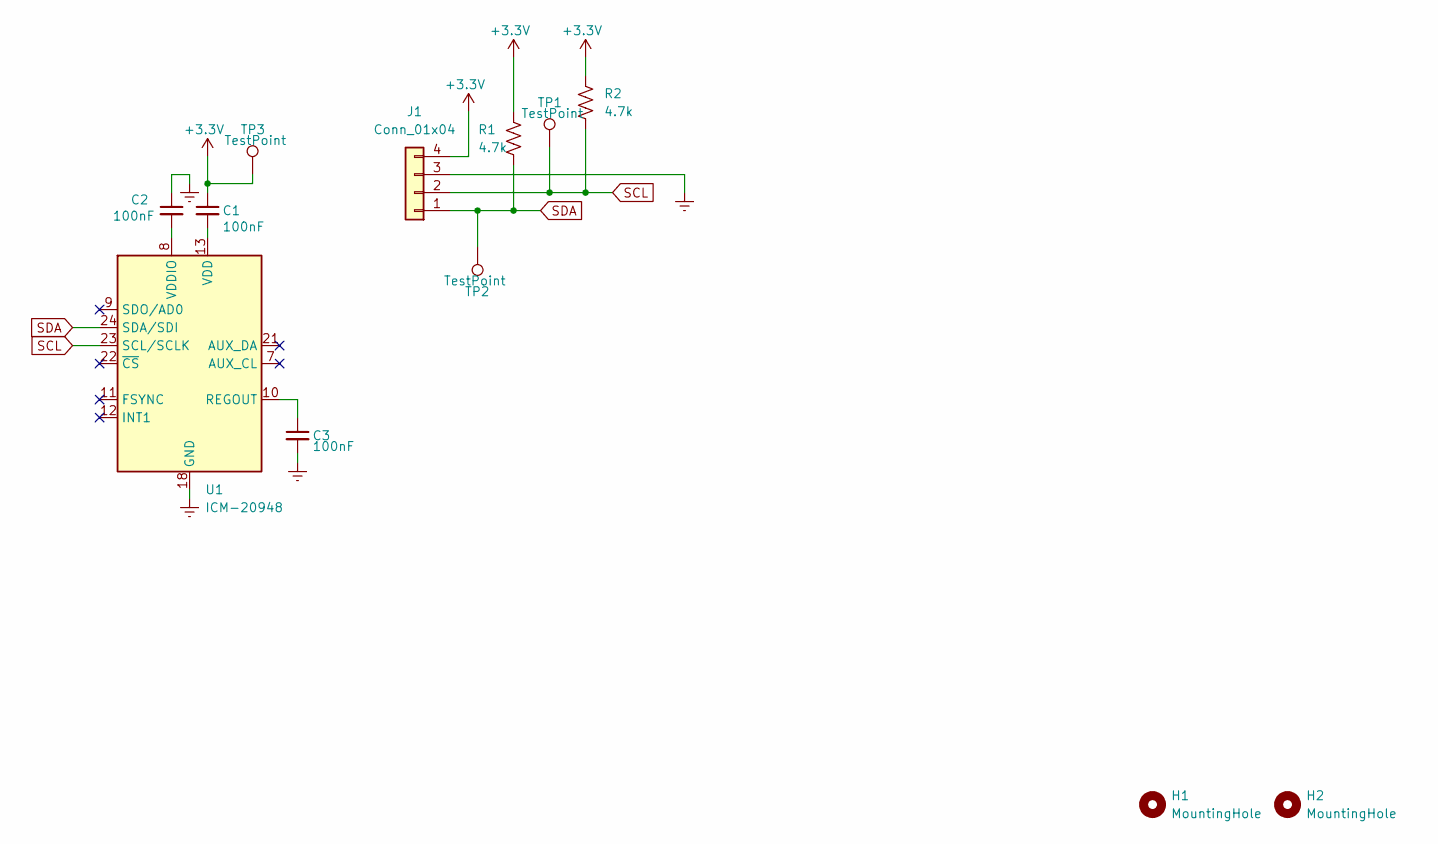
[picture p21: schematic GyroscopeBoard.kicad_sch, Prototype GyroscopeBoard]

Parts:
C1, C2, C3: 100nF; C_0805_2012Metric_Pad1.18x1.45mm_HandSolder; MPN C0603C104K5RACTU
H1, H2: MountingHole; MountingHole_3.2mm_M3_DIN965_Pad
J1: Conn_01x04; CONN_A-6373-04A_MOL
R1, R2: 4.7k; R_0805_2012Metric_Pad1.20x1.40mm_HandSolder; MPN RC0603FR-0710KL
TP1, TP2, TP3: TestPoint; TestPoint_Pad_1.0x1.0mm
U1: ICM-20948; InvenSense_QFN-24_3x3mm_P0.4mm

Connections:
+3.3V: C1.1, J1.4, R1.1, R2.1, TP3.1
GNDREF: C2.1, C3.2, J1.3, U1.18 (GND), U1.20 (GND)
unnamed: C3.1, U1.10 (REGOUT)
unnamed: C1.2, U1.13 (VDD)
unnamed: C2.2, U1.8 (VDDIO)
SCL: J1.2, R2.2, TP1.1, U1.23 (SCL/SCLK)
SDA: J1.1, R1.2, TP2.1, U1.24 (SDA/SDI)

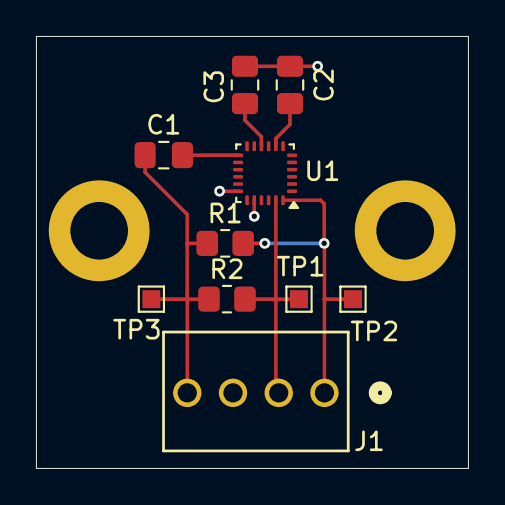
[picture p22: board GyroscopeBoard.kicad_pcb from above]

Board: 2 copper layers, 24.0 x 24.0 mm, 12 parts (0 on the bottom side), 7 nets.

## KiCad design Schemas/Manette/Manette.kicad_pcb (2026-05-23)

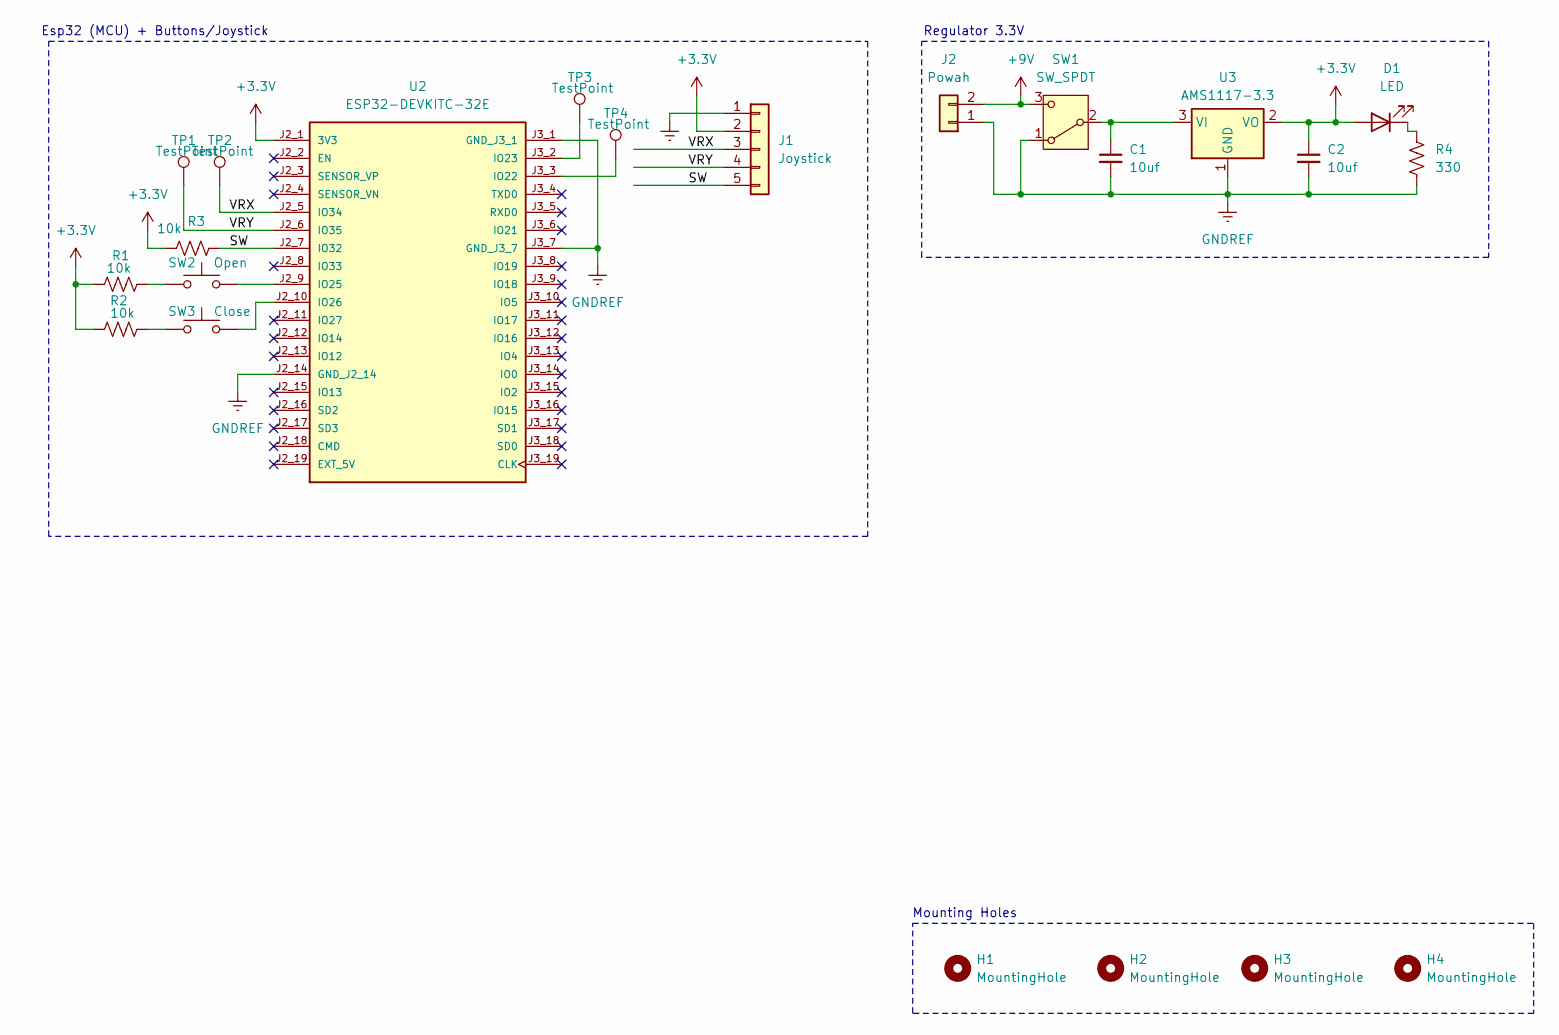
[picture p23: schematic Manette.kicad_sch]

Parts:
C1, C2: 10uf; C_0805_2012Metric_Pad1.18x1.45mm_HandSolder; MPN CL21B106KOQNNNE
D1: LED; LED_0805_2012Metric; MPN LTST-C171KGKT
H1, H2, H3, H4: MountingHole; MountingHole_3.2mm_M3_DIN965
J1: Joystick; PinHeader_1x05_P2.54mm_Vertical; MPN PH1RB-05-UA
J2: Powah; TE_640456-2; MPN 640456-2
R1, R2, R3: 10k; R_0805_2012Metric_Pad1.20x1.40mm_HandSolder; MPN RC0805JR-0710KL
R4: 330; R_0805_2012Metric_Pad1.20x1.40mm_HandSolder; MPN RMCF0805JT330R
SW1: SW_SPDT; SW_JS102011SAQN; MPN JS102011SAQN
SW2: Open; SW_Tactile_SPST_NO_Straight_CK_PTS636Sx25SMTRLFS; MPN PTS636SK25FSMTR LFS
SW3: Close; SW_Tactile_SPST_NO_Straight_CK_PTS636Sx25SMTRLFS; MPN PTS636SK25FSMTR LFS
TP1, TP2, TP3, TP4: TestPoint; TestPoint_Pad_1.5x1.5mm
U2: ESP32-DEVKITC-32E; MODULE_ESP32-DEVKITC-32E; PARTREV 1.4
U3: AMS1117-3.3; SOT-223-3_TabPin2; MPN AMS1117-3.3

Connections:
+3.3V: C2.1, D1.2 (A), J1.2, R1.1, R2.1, R3.1, U2.J2_1 (3V3), U3.2 (VO)
+9V: J2.2, SW1.3 (C)
/SW: J1.5, R3.2, U2.J2_7 (IO32)
/VRX: J1.3, TP2.1, U2.J2_5 (IO34)
/VRY: J1.4, TP1.1, U2.J2_6 (IO35)
GNDREF: C1.2, C2.2, J1.1, J2.1, R4.1, SW1.1 (A), U2.J2_14 (GND_J2_14), U2.J3_1 (GND_J3_1), U2.J3_7 (GND_J3_7), U3.1 (GND)
unnamed: D1.1 (K), R4.2
unnamed: R1.2, SW2.1
unnamed: R2.2, SW3.1
unnamed: C1.1, SW1.2 (B), U3.3 (VI)
unnamed: TP4.1, U2.J3_3 (IO22)
unnamed: TP3.1, U2.J3_2 (IO23)
unnamed: SW2.2, U2.J2_9 (IO25)
unnamed: SW3.2, U2.J2_10 (IO26)

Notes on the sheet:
Regulator 3.3V
Mounting Holes
Esp32 (MCU) + Buttons/Joystick

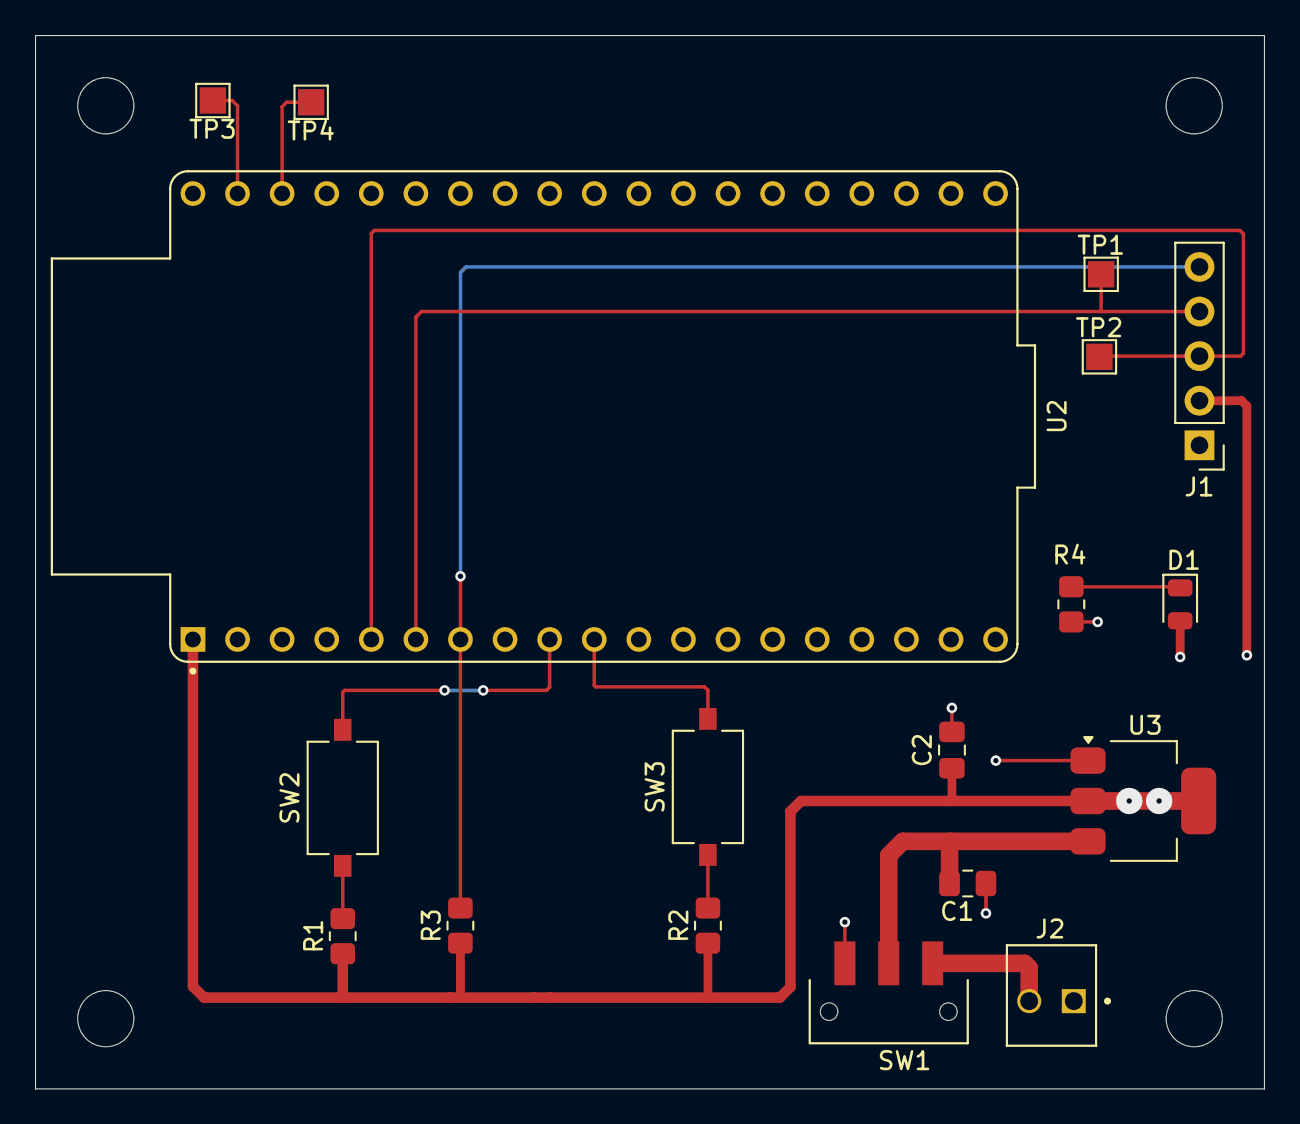
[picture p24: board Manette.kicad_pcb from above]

Board: 2 copper layers, 70.0 x 60.0 mm, 22 parts (0 on the bottom side), 14 nets.

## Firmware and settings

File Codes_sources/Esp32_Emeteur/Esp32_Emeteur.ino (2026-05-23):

/*******************************************************************************
 * ESP32 EMETTEUR - MANETTE DE CONTROLE
 * Projet: Prototype bras continuum
 * Auteur: Jeff Truong
 *
 * Modes:
 * - NORMAL: Joystick X+Y controle 3 moteurs en triangle (continuum arm)
 *           Boutons OPEN/CLOSE = pince
 * - TEST:   Joystick Y fait tourner 1 moteur a la fois
 *           Boutons OPEN/CLOSE = changer moteur
 *
 *           Bouton joystick (clic) = bascule entre les 2 modes
 ******************************************************************************/

#include <WiFi.h>
#include <esp_now.h>
#include <esp_wifi.h>

// --- BROCHES ---
#define JOY_X_GPIO      34
#define JOY_Y_GPIO      35
#define JOY_BTN_GPIO    32
#define BTN_OPEN_GPIO   25
#define BTN_CLOSE_GPIO  26

// --- CONFIGURATION JOYSTICK ---
#define JOY_CENTER    2048
#define JOY_DEADZONE  150
#define JOY_MIN       0
#define JOY_MAX       4095
#define MOTOR_SPEED_MAX 10

// --- MAC RECEPTEUR ---
uint8_t receiverMac[] = {0xF4, 0x65, 0x0B, 0xB5, 0x86, 0xD0};

// --- STRUCTURE PAQUET ---
#pragma pack(push, 1)
typedef struct {
    uint8_t  seq;
    int8_t   joyX;
    int8_t   joyY;
    uint8_t  btnJoy;
    uint8_t  btnOpen;
    uint8_t  btnClose;
    uint16_t motorM1;
    uint8_t  dirM1;
    uint16_t motorM2;
    uint8_t  dirM2;
    uint16_t motorM3;
    uint8_t  dirM3;
    uint8_t  checksum;
} ControlPacket;
#pragma pack(pop)

ControlPacket packet;
unsigned long dernierEnvoi = 0;
const unsigned long INTERVALLE_ENVOI = 30;
bool connexionOK = false;

// --- ETAT MODES ---
uint8_t modeActuel = 0;        // 0 = NORMAL, 1 = TEST
uint8_t moteurTest = 1;        // Moteur selectionne en mode TEST (1-3)
bool dernierEtatJoyBtn = false;
bool dernierEtatOpen   = false;
bool dernierEtatClose  = false;

// --- UTILITAIRES ---
int appliquerDeadzone(int valeur, int centre, int deadzone) {
    int offset = valeur - centre;
    if (abs(offset) < deadzone) return 0;
    return offset;
}

int8_t adcVersPourcent(int valeurAdc, int centre, int deadzone) {
    int offset = appliquerDeadzone(valeurAdc, centre, deadzone);
    if (offset == 0) return 0;
    if (offset > 0) return map(offset, deadzone, JOY_MAX - centre, 0, 100);
    else            return map(offset, -deadzone, JOY_MIN - centre, 0, -100);
}

uint16_t pourcentVersVitesse(int8_t pourcent) {
    if (pourcent == 0) return 0;
    return map(abs(pourcent), 0, 100, 0, MOTOR_SPEED_MAX);
}

uint8_t calculerChecksum(ControlPacket* pkt) {
    return (pkt->seq + pkt->joyX + pkt->joyY +
            pkt->btnJoy + pkt->btnOpen + pkt->btnClose) & 0xFF;
}

void lireBoutons() {
    bool etatJoyBtn = !digitalRead(JOY_BTN_GPIO);  // pull-up: 1 = appuye
    bool etatOpen   = digitalRead(BTN_OPEN_GPIO);   // pull-down: 1 = appuye
    bool etatClose  = digitalRead(BTN_CLOSE_GPIO);  // pull-down: 1 = appuye

    // Bouton joystick = bascule mode (detection front montant)
    if (etatJoyBtn && !dernierEtatJoyBtn) {
        modeActuel = 1 - modeActuel;
        Serial.printf("\n[MODE] === %s ===\n",
            modeActuel == 0 ? "NORMAL (continuum arm)" : "TEST (1 moteur a la fois)");
        if (modeActuel == 1) {
            Serial.printf("[TEST] Moteur selectionne: %d\n", moteurTest);
        }
    }

    // En mode TEST, OPEN/CLOSE change le moteur
    if (modeActuel == 1) {
        if (etatOpen && !dernierEtatOpen) {
            moteurTest++;
            if (moteurTest > 3) moteurTest = 1;
            Serial.printf("[TEST] Moteur: %d\n", moteurTest);
        }
        if (etatClose && !dernierEtatClose) {
            moteurTest--;
            if (moteurTest < 1) moteurTest = 3;
            Serial.printf("[TEST] Moteur: %d\n", moteurTest);
        }
        // En mode TEST, pas de commande pince
        packet.btnOpen  = 0;
        packet.btnClose = 0;
    } else {
        // Mode NORMAL: boutons = pince
        packet.btnOpen  = etatOpen;
        packet.btnClose = etatClose;
    }

    packet.btnJoy        = etatJoyBtn;
    dernierEtatJoyBtn    = etatJoyBtn;
    dernierEtatOpen      = etatOpen;
    dernierEtatClose     = etatClose;
}

void lireJoystick() {
    int brutX = analogRead(JOY_X_GPIO);
    int brutY = analogRead(JOY_Y_GPIO);

    packet.joyX = adcVersPourcent(brutX, JOY_CENTER, JOY_DEADZONE);
    packet.joyY = adcVersPourcent(brutY, JOY_CENTER, JOY_DEADZONE);

    if (modeActuel == 0) {
        // ========== MODE NORMAL - CONTROLE PAR ZONES ==========
        // 6 zones du joystick selon le triangle:
        // M1 = haut, M2 = bas-gauche, M3 = bas-droite
        //
        // Quand on tire un cable, les 2 autres relachent

        int x = packet.joyX;
        int y = packet.joyY;

        // Vitesse selon distance du centre 
        int intensite = max(abs(x), abs(y));
        uint16_t steps = pourcentVersVitesse(intensite);

        // Par defaut tous les moteurs arretes
        packet.motorM1 = 0; packet.dirM1 = 0;
        packet.motorM2 = 0; packet.dirM2 = 0;
        packet.motorM3 = 0; packet.dirM3 = 0;

        if (x >= -100 && x <= -59 && y >= 1 && y <= 100) {
            // UP_LEFT: M2 tire, M1 tire un peu, M3 relache
            packet.motorM1 = steps; packet.dirM1 = 1;
            packet.motorM2 = steps; packet.dirM2 = 1;
            packet.motorM3 = steps; packet.dirM3 = 0;
        }
        else if (x >= -58 && x <= 58 && y >= 58 && y <= 100) {
            // UP: M1 tire, M2 et M3 relachent
            packet.motorM1 = steps; packet.dirM1 = 1;
            packet.motorM2 = steps; packet.dirM2 = 0;
            packet.motorM3 = steps; packet.dirM3 = 0;
        }
        else if (x >= 59 && x <= 100 && y >= 1 && y <= 100) {
            // UP_RIGHT: M3 tire, M1 tire un peu, M2 relache
            packet.motorM1 = steps; packet.dirM1 = 1;
            packet.motorM2 = steps; packet.dirM2 = 0;
            packet.motorM3 = steps; packet.dirM3 = 1;
        }
        else if (x >= 59 && x <= 100 && y >= -100 && y <= 0) {
            // DOWN_RIGHT: M3 tire, M2 et M1 relachent
            packet.motorM1 = steps; packet.dirM1 = 0;
            packet.motorM2 = steps; packet.dirM2 = 0;
            packet.motorM3 = steps; packet.dirM3 = 1;
        }
        else if (x >= -58 && x <= 58 && y >= -100 && y <= -58) {
            // DOWN: M2 et M3 tirent, M1 relache
            packet.motorM1 = steps; packet.dirM1 = 0;
            packet.motorM2 = steps; packet.dirM2 = 1;
            packet.motorM3 = steps; packet.dirM3 = 1;
        }
        else if (x >= -100 && x <= -59 && y >= -100 && y <= 0) {
            // DOWN_LEFT: M2 tire, M3 et M1 relachent
            packet.motorM1 = steps; packet.dirM1 = 0;
            packet.motorM2 = steps; packet.dirM2 = 1;
            packet.motorM3 = steps; packet.dirM3 = 0;
        }
        // Si dans aucune zone (centre/deadzone) = tous a 0 

    } else {
        // ========== MODE TEST - 1 SEUL MOTEUR ==========
        uint16_t steps = pourcentVersVitesse(packet.joyY);
        uint8_t dir    = (packet.joyY >= 0) ? 1 : 0;

        packet.motorM1 = (moteurTest == 1) ? steps : 0;
        packet.dirM1   = (moteurTest == 1) ? dir : 0;
        packet.motorM2 = (moteurTest == 2) ? steps : 0;
        packet.dirM2   = (moteurTest == 2) ? dir : 0;
        packet.motorM3 = (moteurTest == 3) ? steps : 0;
        packet.dirM3   = (moteurTest == 3) ? dir : 0;
    }
}

// --- CALLBACK ESP-NOW ---
void onEnvoi(const wifi_tx_info_t* info, esp_now_send_status_t statut) {
    connexionOK = (statut == ESP_NOW_SEND_SUCCESS);
    if (!connexionOK) Serial.println("[ERREUR] Echec envoi paquet");
}

// --- SETUP ---
void setup() {
    Serial.begin(115200);
    delay(1000);

    Serial.println("\n=== MANETTE ESP32 - BRAS ROBOTISE ===");
    Serial.println("Bouton joystick = bascule MODE NORMAL <-> TEST");
    Serial.println("MODE NORMAL: joystick = bras 3 moteurs, boutons = pince");
    Serial.println("MODE TEST:   joystick Y = 1 moteur, boutons = changer moteur\n");

    pinMode(JOY_BTN_GPIO,   INPUT_PULLUP);
    pinMode(BTN_OPEN_GPIO,  INPUT_PULLDOWN);
    pinMode(BTN_CLOSE_GPIO, INPUT_PULLDOWN);

    analogSetAttenuation(ADC_11db);
    analogSetWidth(12);

    delay(500);
    int testX = analogRead(JOY_X_GPIO);
    int testY = analogRead(JOY_Y_GPIO);
    Serial.printf("[INFO] Centre joystick - X: %d | Y: %d (attendu ~%d)\n",
        testX, testY, JOY_CENTER);

    WiFi.mode(WIFI_STA);
    esp_wifi_set_channel(1, WIFI_SECOND_CHAN_NONE);
    delay(500);
    Serial.print("[INFO] MAC manette: ");
    Serial.println(WiFi.macAddress());

    if (esp_now_init() != ESP_OK) {
        Serial.println("[ERREUR] Initialisation ESP-NOW echouee");
        while(1) delay(1000);
    }

    esp_now_register_send_cb(onEnvoi);

    esp_now_peer_info_t peerInfo = {};
    memcpy(peerInfo.peer_addr, receiverMac, 6);
    peerInfo.channel = 0;
    peerInfo.encrypt = false;

    if (esp_now_add_peer(&peerInfo) != ESP_OK) {
        Serial.println("[ERREUR] Impossible d'ajouter le recepteur");
        while(1) delay(1000);
    }

    Serial.println("[OK] ESP-NOW initialise");
    memset(&packet, 0, sizeof(packet));

    Serial.println("[OK] Manette prete!");
    Serial.println("[MODE] === NORMAL (continuum arm) ===\n");
}

// --- LOOP ---
void loop() {
    unsigned long maintenant = millis();

    if (maintenant - dernierEnvoi >= INTERVALLE_ENVOI) {
        dernierEnvoi = maintenant;

        packet.seq++;
        lireBoutons();
        lireJoystick();
        packet.checksum = calculerChecksum(&packet);

        esp_now_send(receiverMac, (uint8_t*)&packet, sizeof(packet));

        // Debug si actif
        if (packet.motorM1 > 0 || packet.motorM2 > 0 || packet.motorM3 > 0 ||
            packet.btnOpen || packet.btnClose) {
            if (modeActuel == 0) {
                Serial.printf("[NORMAL] X:%d Y:%d | M1:%d D1:%d | M2:%d D2:%d | M3:%d D3:%d | Pince O:%d C:%d\n",
                    packet.joyX, packet.joyY,
                    packet.motorM1, packet.dirM1,
                    packet.motorM2, packet.dirM2,
                    packet.motorM3, packet.dirM3,
                    packet.btnOpen, packet.btnClose);
            } else {
                Serial.printf("[TEST] Moteur:%d | Y:%d | Steps:%d | Dir:%d\n",
                    moteurTest, packet.joyY,
                    moteurTest == 1 ? packet.motorM1 : moteurTest == 2 ? packet.motorM2 : packet.motorM3,
                    moteurTest == 1 ? packet.dirM1 : moteurTest == 2 ? packet.dirM2 : packet.dirM3);
            }
        }
    }
}

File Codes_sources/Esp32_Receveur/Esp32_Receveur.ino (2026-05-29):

/*******************************************************************************
 * RECEPTEUR ESP32 - Mainboard
 * Projet: Prototype bras continuum
 * Auteur: Jeff Truong
 *
 * Recoit ControlPacket depuis manette et transmet au STM32 via UART
 *
 * UART STM32: GPIO16 (RX) / GPIO17 (TX)
 *
 ******************************************************************************/

#include <Arduino.h>
#include <esp_now.h>
#include <WiFi.h>
#include <esp_wifi.h>

// --- UART vers STM32 ---
#define STM32_RX_GPIO  16
#define STM32_TX_GPIO  17
#define STM32_BAUD     115200

// --- STRUCTURE PAQUET (identique emetteur) ---
#pragma pack(push, 1)
typedef struct {
    uint8_t  seq;
    int8_t   joyX;
    int8_t   joyY;
    uint8_t  btnJoy;
    uint8_t  btnOpen;
    uint8_t  btnClose;
    uint16_t motorM1;
    uint8_t  dirM1;
    uint16_t motorM2;
    uint8_t  dirM2;
    uint16_t motorM3;
    uint8_t  dirM3;
    uint8_t  checksum;
} ControlPacket;
#pragma pack(pop)

// --- VALIDER CHECKSUM ---
bool validerChecksum(ControlPacket* pkt) {
    uint8_t calcule = (pkt->seq + pkt->joyX + pkt->joyY +
                       pkt->btnJoy + pkt->btnOpen + pkt->btnClose) & 0xFF;
    return calcule == pkt->checksum;
}

// --- ENVOYER COMMANDE MOTEUR AU STM32 ---
void envoyerMoteur(uint8_t motorId, uint16_t steps, uint8_t direction) {
    if (steps == 0) return;
    uint8_t checksum = motorId ^ (steps & 0xFF) ^ ((steps >> 8) & 0xFF) ^ direction;
    Serial2.write(0xAA);                              // 1. Header (entête)
    Serial2.write(motorId);                           // 2. ID moteur (1-4)
    Serial2.write((uint8_t)(steps & 0xFF));           // 3. Octet bas du nombre de pas
    Serial2.write((uint8_t)((steps >> 8) & 0xFF));    // 4. Octet haut du nombre de pas
    Serial2.write(direction);                         // 5. Direction (0 ou 1)
    Serial2.write(checksum);                          // 6. Checksum pour validation
    Serial.printf("[UART] Moteur %d | Steps: %d | Dir: %d\n", motorId, steps, direction);
}

// --- CALLBACK RECEPTION ESP-NOW ---
void onReception(const esp_now_recv_info_t* info, const uint8_t* data, int longueur) {
    if (longueur != sizeof(ControlPacket)) {
        Serial.printf("[ERREUR] Taille paquet incorrecte: %d (attendu: %d)\n",
            longueur, sizeof(ControlPacket));
        return;
    }

    // Controle continuum arm par zones du joystick:
    // - 6 zones definies dans l'emetteur (UP, UP_LEFT, UP_RIGHT, DOWN, DOWN_LEFT, DOWN_RIGHT)
    // - Quand un cable est tire, les 2 autres relachent
    // - M1 = haut, M2 = bas-gauche, M3 = bas-droite
    // Bouton OPEN/CLOSE = pince (moteur 4)

    ControlPacket pkt;
    memcpy(&pkt, data, sizeof(ControlPacket));

    if (!validerChecksum(&pkt)) {
        Serial.println("[ERREUR] Checksum invalide");
        return;
    }

    Serial.printf("[OK] SEQ:%d | X:%d Y:%d | Open:%d Close:%d\n",
        pkt.seq, pkt.joyX, pkt.joyY, pkt.btnOpen, pkt.btnClose);

    if (pkt.motorM1 > 0) envoyerMoteur(1, pkt.motorM1, pkt.dirM1);
    else                 envoyerMoteur(1, 0, 0);

    if (pkt.motorM2 > 0) envoyerMoteur(2, pkt.motorM2, pkt.dirM2);
    else                 envoyerMoteur(2, 0, 0);

    if (pkt.motorM3 > 0) envoyerMoteur(3, pkt.motorM3, pkt.dirM3);
    else                 envoyerMoteur(3, 0, 0);


    if (pkt.btnOpen) {
        envoyerMoteur(4, 30, 1);
    } else if (pkt.btnClose) {
        envoyerMoteur(4, 30, 0);
    }
}

// --- SETUP ---
void setup() {
    Serial.begin(115200);
    delay(1000);

    Serial.println("\n=== DEMARRAGE RECEPTEUR ESP32 ===");

    Serial2.begin(STM32_BAUD, SERIAL_8N1, STM32_RX_GPIO, STM32_TX_GPIO);
    Serial.println("[OK] UART STM32 initialise (GPIO16/17)");

    WiFi.mode(WIFI_STA);
    esp_wifi_set_channel(1, WIFI_SECOND_CHAN_NONE);
    delay(500);
    Serial.print("[INFO] MAC mainboard: ");
    Serial.println(WiFi.macAddress());

    if (esp_now_init() != ESP_OK) {
        Serial.println("[ERREUR] Initialisation ESP-NOW echouee");
        return;
    }

    esp_now_register_recv_cb(onReception);
    Serial.println("[OK] ESP-NOW initialise");
    Serial.println("[ATTENTE] En attente de commandes...\n");
}

// --- LOOP ---
void loop() {
    if (Serial2.available()) {
        Serial.print("[STM32] Reponse: ");
        while (Serial2.available()) {
            Serial.printf("0x%02X ", Serial2.read());
        }
        Serial.println();
    }
}

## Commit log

2026-05-25 models ajouter
    [base_battery_retainer.stl, base_fixed_segment.stl, base_housing.stl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]
2026-05-29 ajout de commentaire
